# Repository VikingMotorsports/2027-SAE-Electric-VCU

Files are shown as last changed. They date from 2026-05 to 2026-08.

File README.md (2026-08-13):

# Formula SAE EV Vehicle Control System

A distributed **Vehicle Control System (VCS)** for a Formula SAE Electric racecar. The system uses STM32 microcontrollers running Zephyr RTOS for real-time vehicle control, a CAN bus for communication, and a Raspberry Pi for driver and remote telemetry displays.

> **Status:** Active Development

---

## System Overview

The VCS is currently built around two **STM32C092** modules and a Raspberry Pi.

- **Pedal Input Module** — Reads accelerator and brake pedal inputs and transmits them over CAN.
- **Motor Controller Module** — Receives pedal commands over CAN and generates PWM signals for the motor H-bridge.
- **Raspberry Pi Dashboard** — Receives CAN data and displays accelerator and brake inputs to the driver.
- **Remote Pit Dashboard** — Receives vehicle data from the Raspberry Pi over MQTT.

### Architecture

```text

     ┌──────────────────────┐			┌──────────────────────┐
     │   Brake Pedal        │			│   Accelerator Pedal  │
     └──────────┬───────────┘			└──────────┬───────────┘
				│								   │
				└─────────────────┬────────────────┘
                                  │
                                  ▼
                    ┌──────────────────────────┐
                    │   STM32C092              │
                    │   Pedal Input Module     │
                    │                          │
                    │   Zephyr RTOS            │
                    │   ADC → CAN              │
                    └────────────┬─────────────┘
                                 │
                                 │ CAN Bus
                                 │
                ┌────────────────┴────────────────┐
                │                                 │
                ▼                                 ▼
     ┌──────────────────────┐          ┌──────────────────────┐
     │   STM32C092          │          │   Raspberry Pi       │
     │   Motor Controller   │          │   Dashboard          │
     │                      │          │                      │
     │   CAN → PWM          │          │   CAN → Display      │
     └──────────┬───────────┘          └──────────┬───────────┘
                │                                 │
                │ PWM / Control                   │ MQTT
                ▼                                 ▼
     ┌──────────────────────┐          ┌──────────────────────┐
     │   Motor H-Bridge     │          │   Remote Pit         │
     │                      │          │   Dashboard          │
     └──────────────────────┘          └──────────────────────┘

````

---

## Hardware & Software

| Component | Description |
| --- | --- |
| **STM32C092** | Embedded vehicle control modules |
| **Zephyr RTOS**  | Real-time operating system for STM32 modules |
| **CAN Bus** | Communication between vehicle modules |
| **Raspberry Pi** | Dashboard and vehicle telemetry gateway |
| **Vulcan** | CAN interface between the vehicle network and Raspberry Pi |
| **MQTT** | Remote telemetry communication |
| **KiCad** | Electrical and PCB design |

---

## Repository Structure

```text
.
├── Dashboard/              # Raspberry Pi driver dashboard
├── Dashboard Webdisplay/   # Remote pit dashboard
├── Developers_Guide/       # Development documentation
├── PCB/                  	# PCB and electrical design files
├── MQTT/                   # MQTT communication
├── Vulcan/                 # CAN interface and configuration
├── Zephyr_apps/            # STM32C092 Zephyr applications
├── Zephyr_Scripts/         # Build, flash, and development scripts
├── .gitignore
└── README.md
```

---

## Communication

### CAN

The STM32 modules communicate over CAN. The Pedal Input Module sends accelerator and brake values to the CAN network, where they are received by the Motor Controller Module and Raspberry Pi.

```text
Pedal Module
     │
     ├── Accelerator
     └── Brake
          │
          ▼
       CAN Bus
       ┌────┴────┐
       ▼         ▼
Motor Controller  Raspberry Pi
       │             │
       ▼             ├──> Driver Dashboard
    PWM              │
       │             └──> MQTT
       ▼                    │
   H-Bridge                 ▼
                     Remote Pit Dashboard
```

### MQTT

The Raspberry Pi republishes selected CAN data over MQTT, allowing the pit crew to monitor vehicle information remotely.

---

## Current Functionality

The current system provides an end-to-end control and telemetry path:

* Accelerator and brake inputs are read by the Pedal Input Module.
* Pedal values are transmitted over CAN.
* The Motor Controller receives the commands and generates PWM output.
* The Raspberry Pi receives and displays pedal data on the driver dashboard.
* The Raspberry Pi broadcasts the same data over MQTT.
* A remote pit dashboard displays the transmitted vehicle data.

---

## Development

The system is designed to be modular, allowing additional vehicle control and monitoring functionality to be added as development continues.

### Planned Development

* [ ] Expand vehicle telemetry
* [ ] Add additional CAN messages
* [ ] Expand driver dashboard
* [ ] Expand remote pit monitoring
* [ ] Implement fault detection and reporting
* [ ] Add vehicle safety interlocks
* [ ] Develop dedicated VCS hardware
* [ ] Improve CAN diagnostics and logging
* [ ] Complete system-level testing

---

## Project Status

**Early Development / System Integration**

The basic vehicle control and telemetry pipeline is currently operational:

```text
Pedals
  ↓
STM32 Pedal Module
  ↓
CAN Bus
  ├──> STM32 Motor Controller ──> PWM ──> H-Bridge
  │
  └──> Raspberry Pi
          ├──> Driver Dashboard
          │
          └──> MQTT ──> Remote Pit Dashboard
```

Developed as part of a **Formula SAE Electric** racecar project.

```
```

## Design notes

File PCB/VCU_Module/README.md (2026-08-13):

# Viking Motorsports VCU Module

A custom STM32C092RCT6 development and vehicle-control PCB designed specifically for the Viking Motorsports Formula SAE Electric vehicle control system.

The board is designed to fit inside a **Cinch enclosure** and provide a flexible interface between the STM32 microcontroller and the vehicle's external wiring harness. Rather than creating a dedicated PCB for every vehicle-control function, this board provides a common hardware platform that can be configured for different VCU applications.

> **Status:** Hardware Development / Prototype

---

## Board Overview

The VCU Module is a Viking Motorsports-specific development board centered around the **STM32C092RCT6** microcontroller.

The board provides:

- STM32C092RCT6 microcontroller
- CAN bus interface
- Power and ground distribution
- Accessible MCU GPIO and peripheral pins
- Internal configuration headers
- 12-pin external connector
- 20-pin external connector
- Flexible mapping between MCU peripherals and external connector pins
- PCB designed around a Cinch enclosure

The primary design goal is **hardware reuse**. The same PCB can be used for different vehicle-control applications by changing the connections between the MCU peripheral headers and the external enclosure connectors.

---

## Design Concept

The VCU Module separates the vehicle wiring interface from the microcontroller's fixed pin assignments.

```text
                  ┌──────────────────────────────┐
                  │       STM32C092RCT6          │
                  │                              │
                  │   GPIO / ADC / PWM / CAN     │
                  └──────────────┬───────────────┘
                                 │
                         Internal Headers
                                 │
                  ┌──────────────┴───────────────┐
                  │                              │
                  │   User Configurable Wiring   │
                  │                              │
                  └──────────────┬───────────────┘
                                 │
                    ┌────────────┴────────────┐
                    │                         │
              ┌─────▼─────┐             ┌─────▼─────┐
              │ 12-Pin    │             │ 20-Pin    │
              │ Connector │             │ Connector │
              └─────┬─────┘             └─────┬─────┘
                    │                         │
                    └───────────┬─────────────┘
                                │
                       Vehicle Wiring Harness
````

The external connector pinout does not need to be permanently tied to a specific MCU peripheral.

Instead, the board provides internal headers that allow the desired MCU pins to be manually connected to:

* External connector pins
* Power
* Ground
* CAN signals
* Other required vehicle interfaces

This allows the same board design to support different VCU modules without requiring a new PCB layout for each application.

---

## External Interfaces

### 12-Pin Connector

The 12-pin connector provides one of the primary interfaces between the PCB and the vehicle wiring harness.

The individual pins can be assigned to the required MCU signals using the internal configuration headers.

Possible uses include:

* Digital inputs
* Digital outputs
* ADC inputs
* PWM outputs
* Power
* Ground
* Other low-voltage vehicle signals

The exact pin assignment is application-dependent.

### 20-Pin Connector

The 20-pin connector provides additional connections to the vehicle harness.

Like the 12-pin connector, its signals are configurable through the internal headers.

This allows the connector interface to be adapted for different VCU applications while keeping the PCB itself unchanged.

---

## Internal Configuration Headers

One of the primary features of the VCU Module is the collection of internal pin headers.

These headers expose the STM32 peripherals and allow them to be manually connected to the external connector pins.

The headers provide access to:

* MCU GPIO
* ADC-capable pins
* PWM-capable pins
* CAN signals
* 3.3 V / board power
* Ground

This configuration approach allows a single PCB design to be used for multiple vehicle-control modules.

For example, the same board could be configured as:

```text
Pedal Module
    │
    ├── ADC → Accelerator
    ├── ADC → Brake
    └── CAN → Vehicle Network
```

or:

```text
Motor Controller
    │
    ├── CAN → Vehicle Network
    ├── PWM → Motor H-Bridge
    └── GPIO → Control / Enable Signals
```

without changing the underlying PCB design.

---

## CAN Interface

The board includes a dedicated CAN interface for communication with the vehicle control network.

The CAN interface provides:

* CAN TX
* CAN RX
* CAN bus connections
* Access to CAN signals through the board's internal configuration system

The VCU Module is intended to operate as a node on the Formula SAE Electric vehicle CAN network.

CAN message definitions and vehicle communication protocols are documented separately in the main VCU repository.

---

## Power

The board includes dedicated power circuitry and power distribution for the STM32 and associated peripherals.

Power and ground are also made accessible through the internal headers so that external signals can be configured without requiring additional wiring to the PCB.

The power section is separated into its own KiCad schematic sheet for clarity.

---

## Schematic Organization

The KiCad project is divided into several schematic sections:

```text
VCU_Module.kicad_sch
│
├── MCU.kicad_sch
│   └── STM32C092RCT6 and MCU peripherals
│
└── POWER.kicad_sch
    └── Power input and power distribution
```

The top-level `VCU_Module.kicad_sch` integrates the individual schematic sections into the complete board design.

---

## Intended Use

This board is intended to serve as the standard **Viking Motorsports VCU development platform**.

The goal is to avoid designing a new PCB whenever a new vehicle-control function requires a different combination of MCU peripherals.

Instead:

1. Select the required MCU peripherals.
2. Connect those peripherals to the appropriate internal headers.
3. Connect the headers to the desired external connector pins.
4. Install the board into the Cinch enclosure.
5. Develop the corresponding Zephyr application.

This creates a common hardware platform for future VCU development.

---

## Example Applications

The board can be configured for a variety of vehicle-control functions, including:

### Pedal Input Module

```text
Accelerator ──> ADC
Brake ────────> ADC
CAN ──────────> CAN Interface
```

### Motor Controller Module

```text
CAN ──────────> CAN Interface
PWM ──────────> Motor H-Bridge
GPIO ─────────> Enable / Control
```

### Future VCU Modules

The configurable hardware architecture allows future modules to be developed without creating a completely new PCB for each function.

---

## Enclosure

The PCB is designed to fit within a **Cinch 5810130065 4x3.35 ME enclosure** and utilizes the **Cinch 5810132011 32 pos. ME-MX header**

The external 12-pin and 20-pin Molex MX150 connectors provide the interface to the vehicle wiring harness while the configurable headers remain accessible inside the enclosure.

This provides a clean separation between:

* Vehicle wiring
* PCB hardware
* MCU peripheral assignment
* Firmware configuration

---

## Development Status

**Current Status: Prototype / Hardware Development**

The KiCad project currently contains a complete schematic and PCB design for the VCU Module.

Before deployment in the vehicle, the design should undergo:

* Electrical design review
* KiCad ERC verification
* PCB DRC verification
* Connector pinout verification
* Power integrity testing
* CAN interface testing
* MCU programming/debug testing
* Enclosure fit verification
* Vehicle-level testing

The connector pin assignments should be considered **application-specific** until finalized for a particular VCU module.

---

## Related Software

Firmware for the STM32C092-based vehicle control modules is located in the main repository under:

```text
Zephyr_apps/
```

The VCU software currently includes separate applications for vehicle-control functions such as the pedal input and motor controller modules.

---

## Design Philosophy

The VCU Module is designed around three principles:

**Reusable Hardware**
One PCB can support multiple vehicle-control applications.

**Configurable Interfaces**
MCU peripherals can be mapped to the external connector pins using internal headers.

**Vehicle Integration**
The board provides a consistent physical and electrical interface for the Viking Motorsports vehicle control system.

---

**Viking Motorsports — Formula SAE Electric**

*Custom hardware for the 2027 SAE Electric Vehicle Control System.*

## Documentation Links

*https://www.cinch.com/products/enclosures/enclosures/5810130065*

*https://www.cinch.com/products/enclosures/headers/5810132011*

*https://www.st.com/en/microcontrollers-microprocessors/stm32c092rc.html*

## Documentation Files

| Filename | Notes |
| --- | --- |
| README.pdf | This README file |
| VCU_Module-outline.dxf | Board outline (with holes) in DXF format |
| VCU_Module-pcba.step | 3D model of PCBA (with components) |
| VCU_Module-render-bot.jpg | Render of the top of the 3D model |
| VCU_Module-render-bot.jpg | Render of the bottom of the 3D model |
| VCU_Module-schematic.pdf | PDF of board schematics |

## Contact Information

- Website: *website*
- Email: *email*

## Board Renders

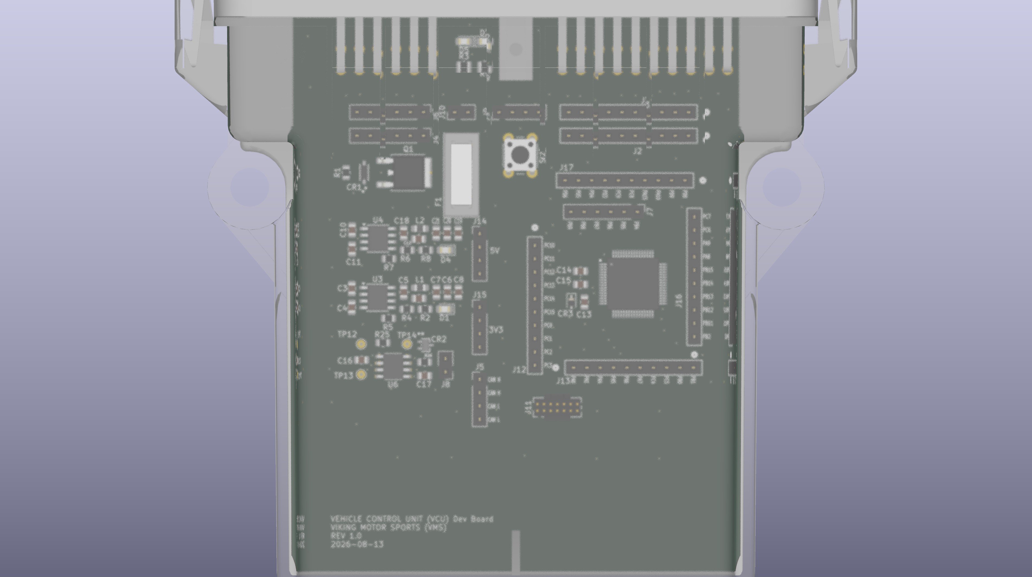
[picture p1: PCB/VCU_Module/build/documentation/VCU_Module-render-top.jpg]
Render of the top of the 3D model

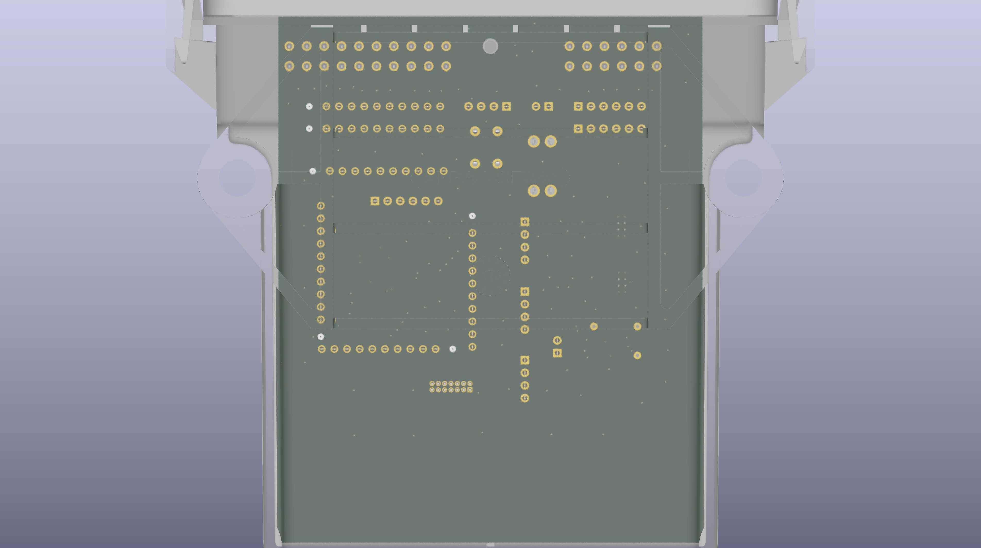
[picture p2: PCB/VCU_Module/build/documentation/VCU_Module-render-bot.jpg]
Render of the bottom of the 3D model


\newpage

# Printed Circuit Board (PCB) Fabrication Information

---
title: "**Viking MotorSports VCU Module**"
subtitle: |
  **Fabrication and Assembly Information**\
  For build TIME-STAMP
fontsize: 10pt
geometry:
  - margin=0.5in
toc: true
toc-depth: 2
colorlinks: true
urlcolor: blue
---

## Board Info

- 2 layer board
- Bounding box is *TBD*
- Board thickness is 1.59 mm (0.063 inch)

## Board Requirements

- Design Rules
    - Minimum Trace / Space design rulea: 0.1524 mm (6.0 mil) / 0.1524 mm (6.0 mil)
    - Outer dimension router tolerance: +/- 0.254 mm (10.0 mil)
    - Hole placement tolerance: +/- 0.075 mm (3.0 mil)
- Drills
   - Drill Positional Tolerance: 0.051 mm (2.0 mil)
   - Drill Size tolerance: +/- 0.064 mm (2.5 mil)
- Plated/Un-plated holes
  - There are no un-plated (NPT) holes
  - There are 96 plated through (PTH) holes
  - PTH minimum diameter: 0.254 mm (10 mil)
  - PTH minimum annulus: 0.102 mm (4 mil) radius
- Outline/Routing
  - No requirements.
- Slots
  - There are no slots.
- Cutouts
  - There are no cutouts
- There are 3 fiducials on the top layer.
- Panel tabs ("mouse bites")
   - Card edges must be smooth; no mouse bites or other intrusions into the card outline.
   - If external mouse bites are required, minimize and customer will remove by hand before assembly.
- If not otherwise specified, build to IPC 6012 Class 2 or better.

## Materials

- No requirements for materials.
- Copper Surface treatment should be ENIG, althogh immersion Silver is acceptable.
- White silkscreen on top and bottom surface
- Taiyo PSR-4000 or equivalent soldermask on top and bottom, no requirements for color.

## Stack Up

- Any FR4 like material is acceptable.
- 1 oz Copper on top and bottom layers
- 1.6 mm thick when done (1/16 inch)

## Array / Panel Information

- Coordinate with Contract Manufacturer (CM) for optimal size of this panel.
- If no feedback from CM, then produce single boards (no panel).

## Fabrication Files

### IPC-2581 File

| Filename | Notes |
| --- | --- |
| VCU_Module-ipc2581.xml | IPC-2581 board information file |

### Legacy PCB Files

| Filename | Notes |
| ---| --- |
| VCU_Module-Edge_Cuts.gbr | RS274X file for the dimension (outline) layer |
| VCU_Module-F_Silkscreen.gbr | RS274X file for the top silkscreen |
| VCU_Module-F_Mask.gbr | RS274X file for the top soldermask |
| VCU_Module-F_Cu.gbr | RS274X file for the top copper layer |
| VCU_Module-In1_Cu.gbr | RS274X file for the layer 2 copper |
| VCU_Module-In2_Cu.gbr | RS274X file for the layer 3 copper |
| VCU_Module-B_Cu.gbr | RS274X file for the bottom copper layer |
| VCU_Module-B_Mask.gbr | RS274X file for the bottom soldermask |
| VCU_Module-B_Silkscreen.gbr | RS274X file for the bottom silkscreen |
| VCU_Module-NPTH.drl | Excellon file for non-plated through holes |
| VCU_Module-PTH.drl | Excellon file for plated through holes | 

\newpage

# Printed Circuit Board Assembly (PCBA) Information

## Assembly Info

- All components are on the top side of the board.
- This PCBA has two components that are SMT components with through-hole mechanical leads.

## Assembly Requirements

- Assemble to IPC Class 2 or better
- Solder paste can be ROHS or leaded.
- No clean, or Aqueous flux and wash, can be used.
- No conformal coating.

## Component Specific Assembly Information

- None

## Assembly Files

### IPC-2581 File

| Filename | Notes |
| --- | --- |
| VCU_Module-ipc2581.xml | IPC-2581 board information file |

### Bill of Materials (BOM)

| Filename | Description |
| --- | --- |
| VCU_Module-bom.csv | BOM in Comma Separated Variable format |

### Solder Paste Stencils

| Filename | Notes |
| --- | --- |
| VCU_Module-B_Paste.gbr | RS274X file for top/front solder paste stencil |
| VCU_Module-F_Paste.gbr | RS274X file for bottom/back solder paste stencil |

### Mounting/Placement Location

| Filename | Description |
| --- | --- |
| VCU_Module-3u.pos | Pick and place locations for components |

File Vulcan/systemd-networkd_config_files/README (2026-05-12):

This config file tells the linux system to automatically configure and initialize the can0 device on startup and/or hotplug

save the .network file in this folder into /etc/systemd/network/

Then run the following command:

sudo systemctl restart systemd-networkd

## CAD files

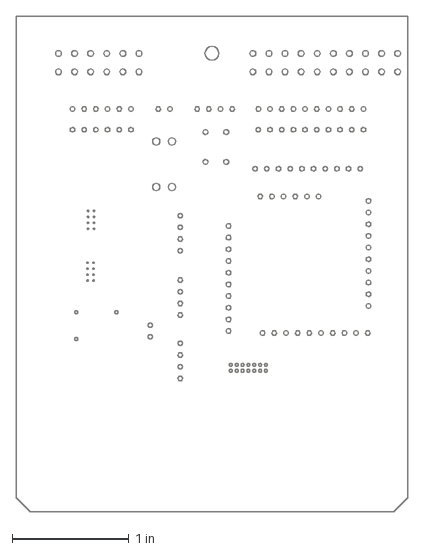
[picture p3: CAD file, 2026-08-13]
PCB/VCU_Module/build/documentation/VCU_Module-outline.dxf
3.35 x 4.25 in

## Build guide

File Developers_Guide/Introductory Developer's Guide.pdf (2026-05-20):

Hello new developer! Here’s your guide to getting started with writing firmware for the VMS VCU

### system!

### A couple orders of business before starting, here’s the tools we’re going to use:

- STM32C092RC boards STM32C092RC | Product - STMicroelectronics (https://www.st.com/en/microcontrollers-microprocessors/stm32c092rc.html)
- Zephyr RTOS Getting Started Guide — Zephyr Project Documentation (https://docs.zephyrproject.org/latest/develop/getting_started/index.html)
- Your choice IDE (VS Code always a favorite) Tutorial: Get started with Visual Studio Code (https://code.visualstudio.com/docs/getstarted/getting-started)
- CAN FD communication protocol Microchip University CAN (https://mu.microchip.com/page/interface)

These tools were chosen for their versatility, price, featureset, and ease of development. It’s recommended that you at least look at the C0 datasheet, learn how to set up Zepyhr dev tools and the flashing utility, get familiar with your IDE, and at least watch the CAN basics course in full if not the CAN development course before continuing. “Give me six hours to chop down a tree and I’ll spend the first four sharpening the axe.” - Lincoln, presumably.
The Zephyr getting started guide is a great starting point for setting up development tools, however to break into CAN the Zephyr CAN driver page is an excellent resource with CAN samples that can be built upon.
- Zephyr CAN page: Controller Area Network (CAN) — Zephyr Project Documentation (https://docs.zephyrproject.org/latest/hardware/peripherals/can/index.html)
- CAN samples main: zephyr/samples/drivers/can at main · zephyrproject-rtos/zephyr · GitHub (https://github.com/zephyrproject-rtos/zephyr/tree/main/samples/drivers/can) In the samples (“samples” under the CAN controller title) there is a counter and a babbling example. Either of these examples are a good base for creating a CAN program that can filter and send messages on a bus.

Zephyr RTOS was partially chosen for the ability to use the CAN controller in real-time though the CAN shell.

### - Zephyr Shell basics: https://dev.blues.io/blog/zephyr-use-shells-for-prototyping/ - Using Zephyr and Shell on Linux: https://michaelangerer.dev/zephyr/2023/02/12/zephyr-basics-shell.html

- Zephyr Shell Official Site: https://docs.zephyrproject.org/latest/services/shell/index.html

### - CAN shell commands: https://docs.zephyrproject.org/latest/hardware/peripherals/can/shell.html how

## Reading Sensors

At this point you should already have gone through the Zephyr RTOS Getting Started Guide — Zephyr Project Documentation. (https://docs.zephyrproject.org/latest/develop/getting_started/index.html) If not, do this first and get blinky running on your board.

Next, download the appropriate documentation for the board you are using, below you will find the datasheets for the nucleo c092rc (MB2046)

Nucleo_c092rc board user manual: https://www.st.com/resource/en/user_manual/um3353-stm32-nucleo64-board-mb2046-stmicroel ectronics.pdf (https://www.st.com/resource/en/user_manual/um3353-stm32-nucleo64-board-mb2046-stmicroelectronics.pdf)
Zephyr documentation for Nucleo_c092rc board: https://docs.zephyrproject.org/latest/boards/st/nucleo_c092rc/doc/index.html

### Potentiometer

We will set up the board to read from a potentiometer using one of the boards analog inputs paired with an adc sample. The following steps will get you started:

1.) Navigate to your zephyr project directory and find the adc_dt sample, this should be in <zephyrproject>/zephyr/samples/drivers/adc/adc_dt.

2.) Open the boards folder to see if there is an existing overlay for your board. If so, skip to step 4, if not we will make one.

3.) Create board Overlay: The board overlays help make zephyr more portable by allowing you to define key parameters for the board you are using without having to modify the main source code.
a.) First, copy a similar board overlay and rename it to match your board, I copied the nucleo_c071rb and renamed it to nucleo_c092rc

b.) Next, Open the overlay and find the section that defines the adc input channels which should look like this:

c.) find your boards dts file, in <zephyrproject>/zephyr/boards/ (for c092rc, it should be <zephyrproject>\zephyr\boards\st\nucleo_c092rc\nucleo_c092rc.dts)

The dts file defines hardware configuration for the board, including peripheral routing. We need to find what pins are connected to the adc by default.

d.) Here is a sample from the c092 .dts file:

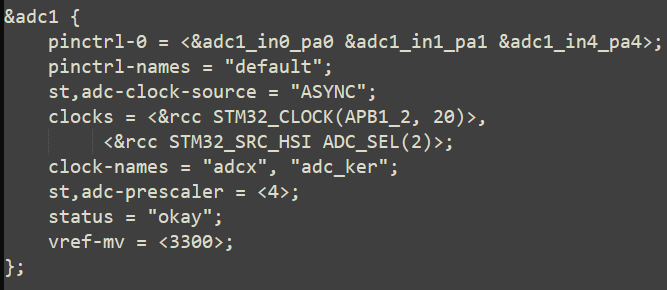
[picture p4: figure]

As you can see, the &adc1 peripheral is configured as an input to pa0, pa1, pa4
This matches the definitions in the c071 overlay which I copied, so no changes were needed. However, if you needed or wanted to change the input ports this is where you would do it.

4.) You now should have a board overlay for your board. If you haven't already, find and open your boards dts file in <zephyrproject>/zephyr/boards/ and find the adc peripheral section. Take note of the pin names that it is connected to. (for c092rc example above, pa0, pa1, pa4)

5.) Open the documentation for your board and search the pin names that you just found and note their location on the board. Also take note of the input range! (for c092rc, user-manual (https://www.st.com/resource/en/user_manual/um3353-stm32-nucleo64-board-mb2046-stmicroelectronics.pdf) page 23, CN7/Pins 28,30,32)

6.) Finally, connect your sensor to one of the pins you identified, build and flash adc_dt sample, and use the serial monitor of your choice to monitor the output. You should see something like the image below

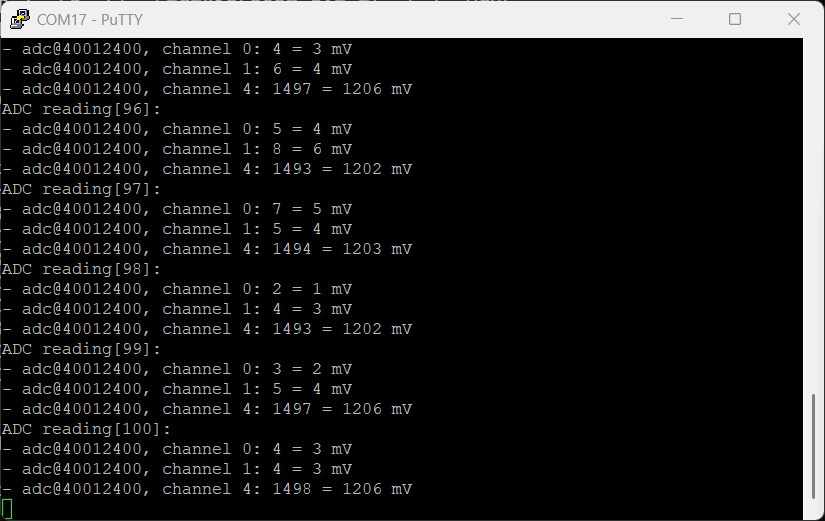
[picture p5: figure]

## ADC Input -> CAN Message

Before starting on this, you should have loaded and successfully ran both the adc and CAN counter samples on your board. Now we will combine these two samples into a new application that transmits input data onto the CAN bus.

1. First, create a copy of the can counter sample folder and rename it whatever you like. It should have the source code, boards folder, config files, etc.
2. Now we need to add all of the stuff in order to use ADC functionality in the application. This just means copying dissimilar things over from the adc_dt sample but here’s a list of things to change:
a. Boards folder: copy the overlay for your board from adc_dt to the new app
b. CMakeLists: add ADC package to the list of required packages
c. Kconfig: add ADC calibration requirement
d. prj.conf: add ‘CONFIG_ADC=y’
3. With the ADC functionality now enabled and configured for use in the new app, we can move on to the source code.

Copy everything from the adc_dt main that is not already in our main file. There are some new header files and definitions, a function called adc_dt_spec, and all of the code in main to configure and read from the ADC.

Within the main function, I put the ADC reading code inside the while(1) loop, after the change led section and before the counter message.

4. At this point, you should have an app that builds and runs but it will be printing the ADC values to the terminal directly instead of over CAN and it will still be sending the counter messages over the bus. Modify the main.c as follows:
a. Comment out all of the print statements in the while 1 loop
b. Move the can_send and UNALIGNED_PUT calls inside of the adc loop at the end
c. Change the UNALIGNED_PUT command for the counter message so that it uses val_mv (adc_input) instead of ‘counter’
d. Scroll up and find the rx_thread function. Everything should be functional as it is, but you can change the print statements so they output more appropriate messages like ‘adc value received’ or whatever you like.

This is the function where you filter messages and define what to do with those messages when you receive them.

5. Finally, build and flash to your board and your board should now read an adc input and output it onto the CAN bus

## Receiving CAN Messages

In order to receive data we need to create a filter for the desired message id, add that id to the message queue, and define what to do with it once it is received.

First, we need to create the new message ID, you should see something like this at the top of an existing CAN app:

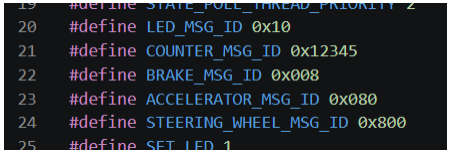
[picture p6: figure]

You can define the new message however you want, just remember that the message ID contains an implicit priority with lower IDs getting serviced first

Next, in the rx_thread function you should see an existing filter struct that looks like this

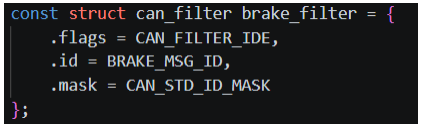
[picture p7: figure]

TBD/Maybe not needed since we moved to Vulcan

## Setting up vulcan and candlelight socketCAN

See the copperforge vulcan documentation here: https://copperforge.cc/docs/index.html For initial setup of the vulcan.

Download the latest .bin file from the candlelight page https://gitlab.com/Copperforge/Public/vulcan_firmware/vulcan_fw_candlelight/-/releases/

SocketCAN can only be run on a linux system, we have yet to figure out how to get it to work on windows.

On your linux system you will need to install can-utils and dfu-util which can be done be running the following commands

Sudo apt install dfu-util
Sudo apt install can-utils

Then just follow the copperforge setup guide to flash the candlelight socketCAN software to the vulcan

## Using socketCAN device

Once you have flashed the vulcan with the software, you should be able to see the can device on your system to check. In the terminal, run:

ip link show

For more information, run

ip -details link show can0

This will tell you bitrate, samplepoint, and other configuration information on the device

This should show all of the network devices available and you should now have a device labeled “can0”

If this is your first time plugging it in, it will show “down” meaning it is inactive

To activate the can device run the command

sudo ip link set can0 up type can bitrate 500000

Now if you run ip -detatils link show can0 again, you should see that the bus is “up” and bitrate is set for 500000.

You should also see that the status is “ERROR-ACTIVE” which means the CAN bus is working properly.

You can now run candump can0 in one terminal window while you send can messages in a separate window using cansend can0 <MSG_ID>#<PAYLOAD>

For example,
Cansend can0 123#deadbeef

Which should display a message with ID 123 and data bytes DE AD BE EF in the candump window.

If it any time messages are not making it through, check to see if the bus status is “ERROR-PASSIVE” using the ip -details link command. This means that the device has received too many error messages and has errored out.

You can reset the bus by running
sudo ip link set can0 down
Then
sudo ip link set can0 up

You now have a functioning CAN network device, yay!

## Configuring auto initialize for socketCAN device

To have the CAN bus automatically initialize we added a systemd-networkd file to tell the linux system to bring the bus up when it is recognized. This works for hotplugging the vulcan too!

In the VCU GitHub, find the configuration file labeled “80-can.network”

Copy this file to your system network files by running the following

sudo cp 80-can.network /etc/systemd/network/

Then run the command

sudo systemctl restart systemd-networkd

Your can device should now be activated and your linux system should automatically bring the CAN bus up on startup or hotplug.

Confirm that the bus is active and working by ensuring that it says “UP” and “ERROR-ACTIVE” when you run ip -details link show can0

## Using SocketCan on Windows

This is kind of a pain and not at all necessary but if you are determined to develop on a windows system like I was then it isn't too hard to get set up.

You should probably know a little bit about building a Linux kernel before attempting but the guide below is pretty easy to follow regardless.

https://gist.github.com/manavortex/cdaf9540784808e5848cbec744d49a19

I had a couple issues when doing this:

1.) I was missing a tool required for building the kernel (it will throw an error during building and tell you which module is missing)
2.) The CAN device drivers menu was on a different page than what they show in the guide. (for me, it was in device drivers -> networking drivers -> CAN drivers, or something like that)
3.) You will also want to enable the usb-CAN driver that your device uses, for candlelight socketCAN on the vulcan, it is gs_usb (Geschwister Schneider)

Other than that, you will need to use the windows usbipd tools to attach usb devices to WSL

Usbipd list (to find bus id)
Usbipd bind -b <bus-id>
Usbipd -w -b <bus-id>

Then if you should see the device in WSL using lsusb and ip link show.

## Writing a New Module using VCUmodule in Zephyr

This application is designed to split up all of the functionality needed for the entire car into separate .c/.h files so that you can only include what is necessary for a specific module. Each API contains essential functions for setting up and using that specific feature.

More information on specific features can be found in the .h and .c files

See the following outline for writing a new module.

1.) Copy VCUmodule to your zephyr workspace

2.) At the time of writing this, the nucleo_c092rc is the only board that we have written an overlay for. If you are using a different board, you will need to create a new one specific to your board that supports the functionality desired.

3.) Open the CMakeLists.txt file, you should see something like this:

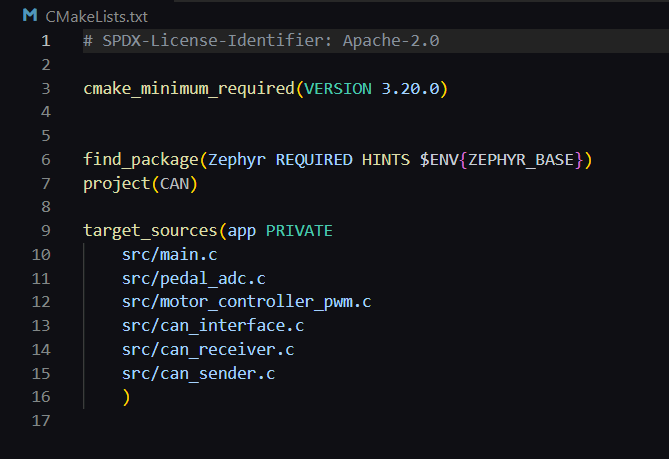
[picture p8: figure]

This is where you will tell CMake which .c files you will be using for your module. You can delete the ones not needed for your module.
Similarly, you can add/remove the .h files from main as needed

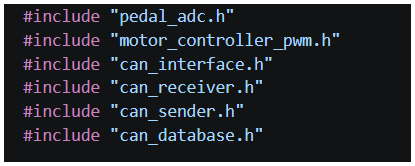
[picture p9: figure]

4.) Now you are ready to write main and add any functionality needed for the new module.

The main.c that you started with should serve as a good example of how to interact with the various APIs but each one also has fairly good documentation inside for where to add stuff.

5.) CAN Functionality

It should be fairly straightforward getting CAN functionality added with the APIs as they are well commented, but I’ll explain each file briefly since there are a few.

can_database.h
This file simply contains the CAN message IDs and and comments about how they are used

can_interface
This contains all generic CAN initialization and is needed if CAN functionality will be utilized in the module

can_receiver
Contains functions for receiving data over the CAN bus. This is only needed if you need to receive messages from the bus.

Inside you will have to define filters for any message IDs that you add in order to receive them

Optionally, you can define what to do when specific messages are received here as well

can_sender
Contains functions for sending data over the CAN bus. This is only needed if you are sending data over the bus.

You should define CAN frames for the MSG IDs you are sending here. The sending function will default to 8 byte payload, std 11-bit ID, etc. if not defined.

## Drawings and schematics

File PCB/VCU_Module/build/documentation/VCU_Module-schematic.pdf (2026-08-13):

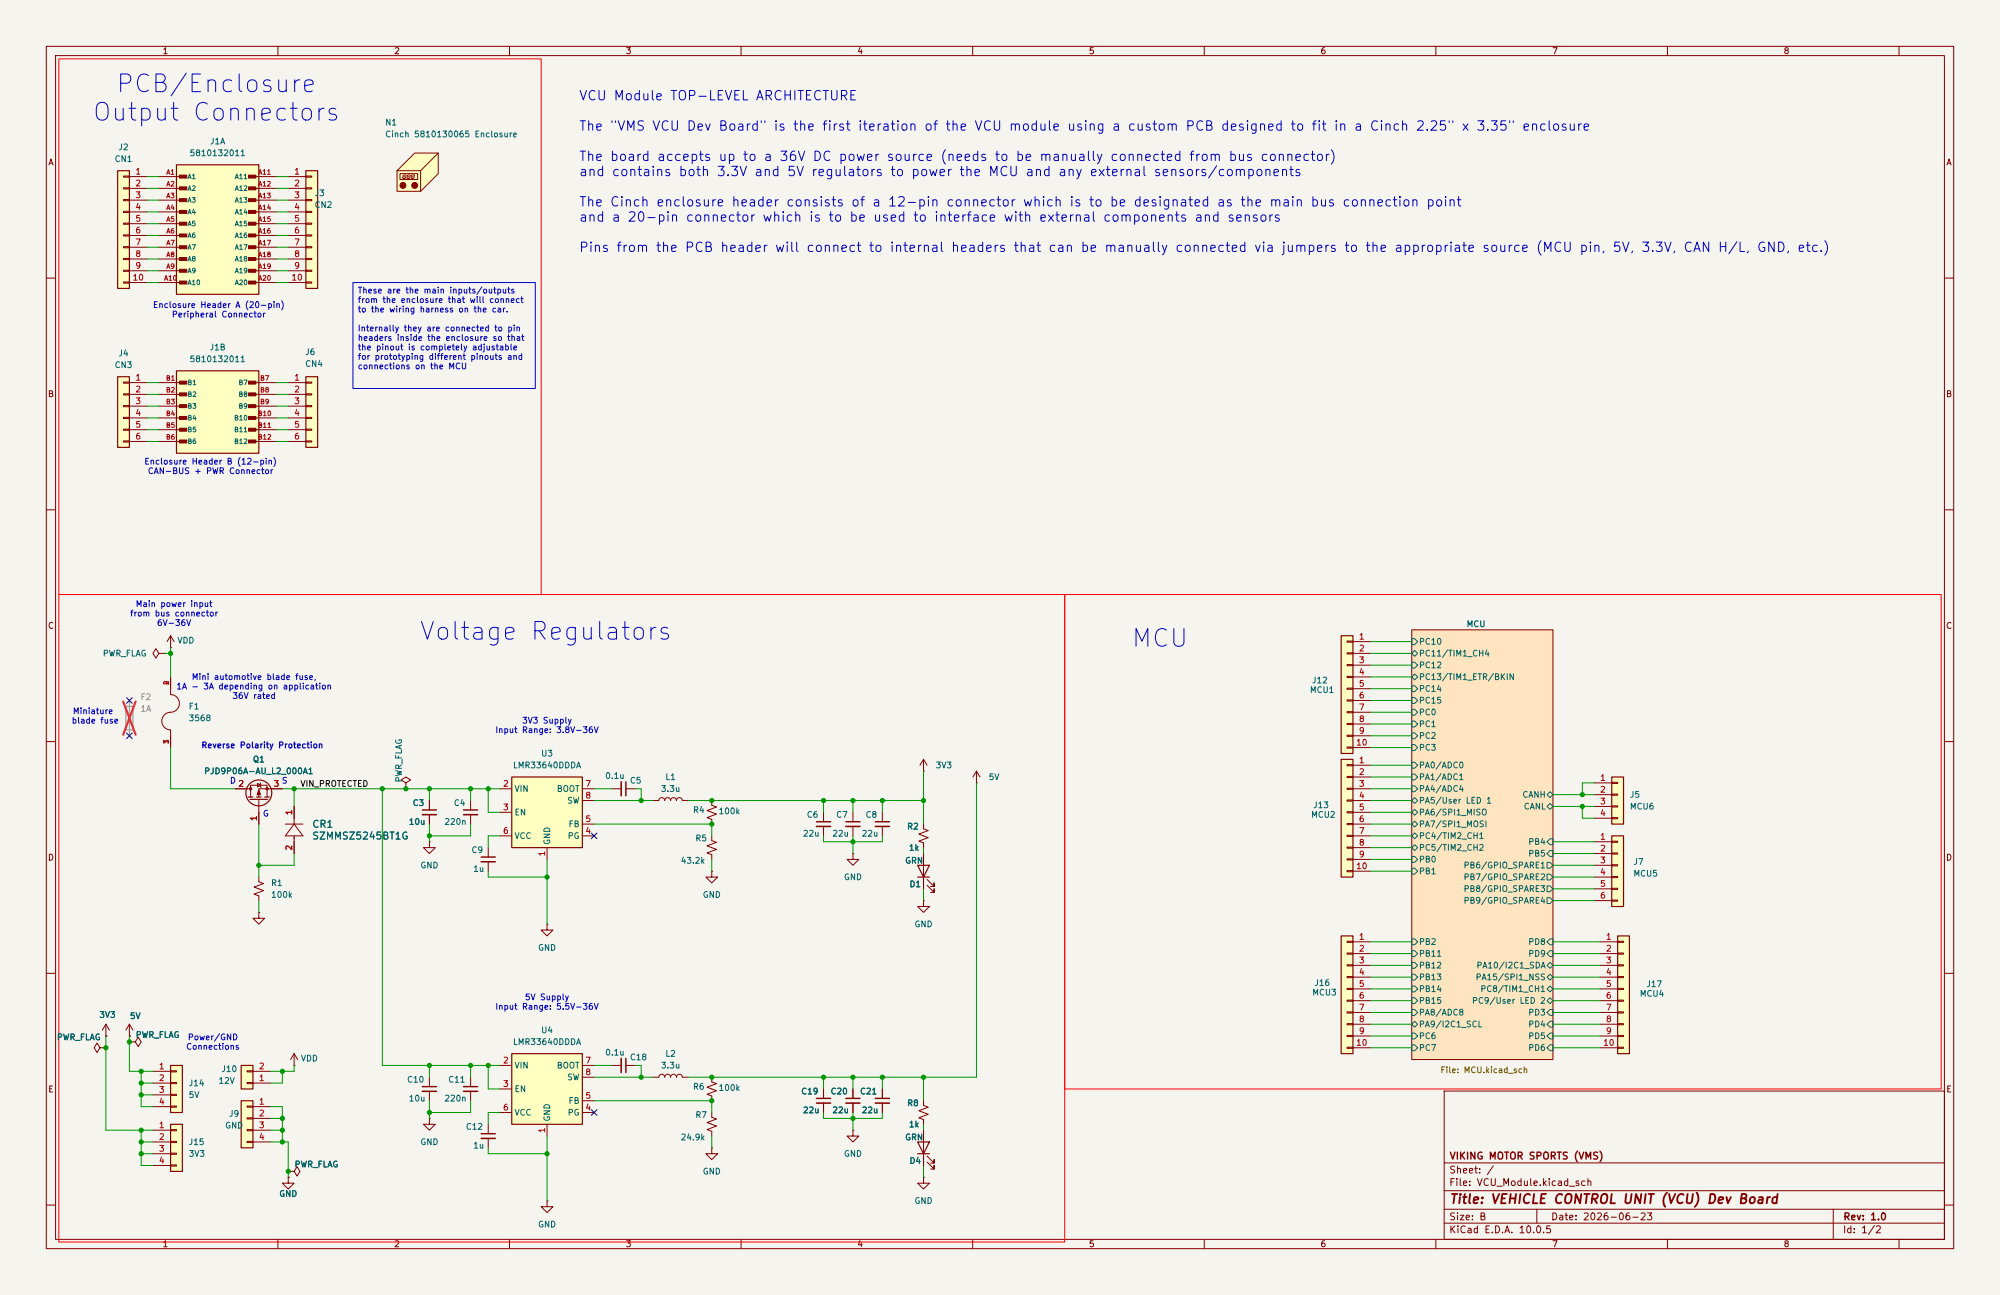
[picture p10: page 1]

Peripheral Connector PCB/Enclosure
Output Connectors

VCU Module TOP-LEVEL ARCHITECTURE

The "VMS VCU Dev Board" is the first iteration of the VCU module using a custom PCB designed to fit in a Cinch 2.25" x 3.35" enclosure

The board accepts up to a 36V DC power source (needs to be manually connected from bus connector)
and contains both 3.3V and 5V regulators to power the MCU and any external sensors/components

The Cinch enclosure header consists of a 12-pin connector which is to be designated as the main bus connection point
and a 20-pin connector which is to be used to interface with external components and sensors Pins from the PCB header will connect to internal headers that can be manually connected via jumpers to the appropriate source (MCU pin, 5V, 3.3V, CAN H/L, GND, etc.)

These are the main inputs/outputs
from the enclosure that will connect
to the wiring harness on the car.

Internally they are connected to pin
headers inside the enclosure so that
the pinout is completely adjustable
for prototyping different pinouts and
connections on the MCU Voltage Regulators

Main power input
from bus connector 6V-36V Reverse Polarity Protection D Mini automotive blade fuse, 1A - 3A depending on application 36V rated
LMR33640DDDA GND

PB9/GPIO_SPARE4 PB11 PB12 PB13 PB14 PB15 PC0 PC1 PC2 PC3 PC4/TIM2_CH1
VIKING MOTOR SPORTS (VMS) CANH

10 | 10

Sheet: /
File: VCU_Module.kicad_sch
Title: VEHICLE CONTROL UNIT (VCU) Dev Board

Size: B | Rev: 1.0
KiCad E.D.A. 10.0.5 | Id: 1/2

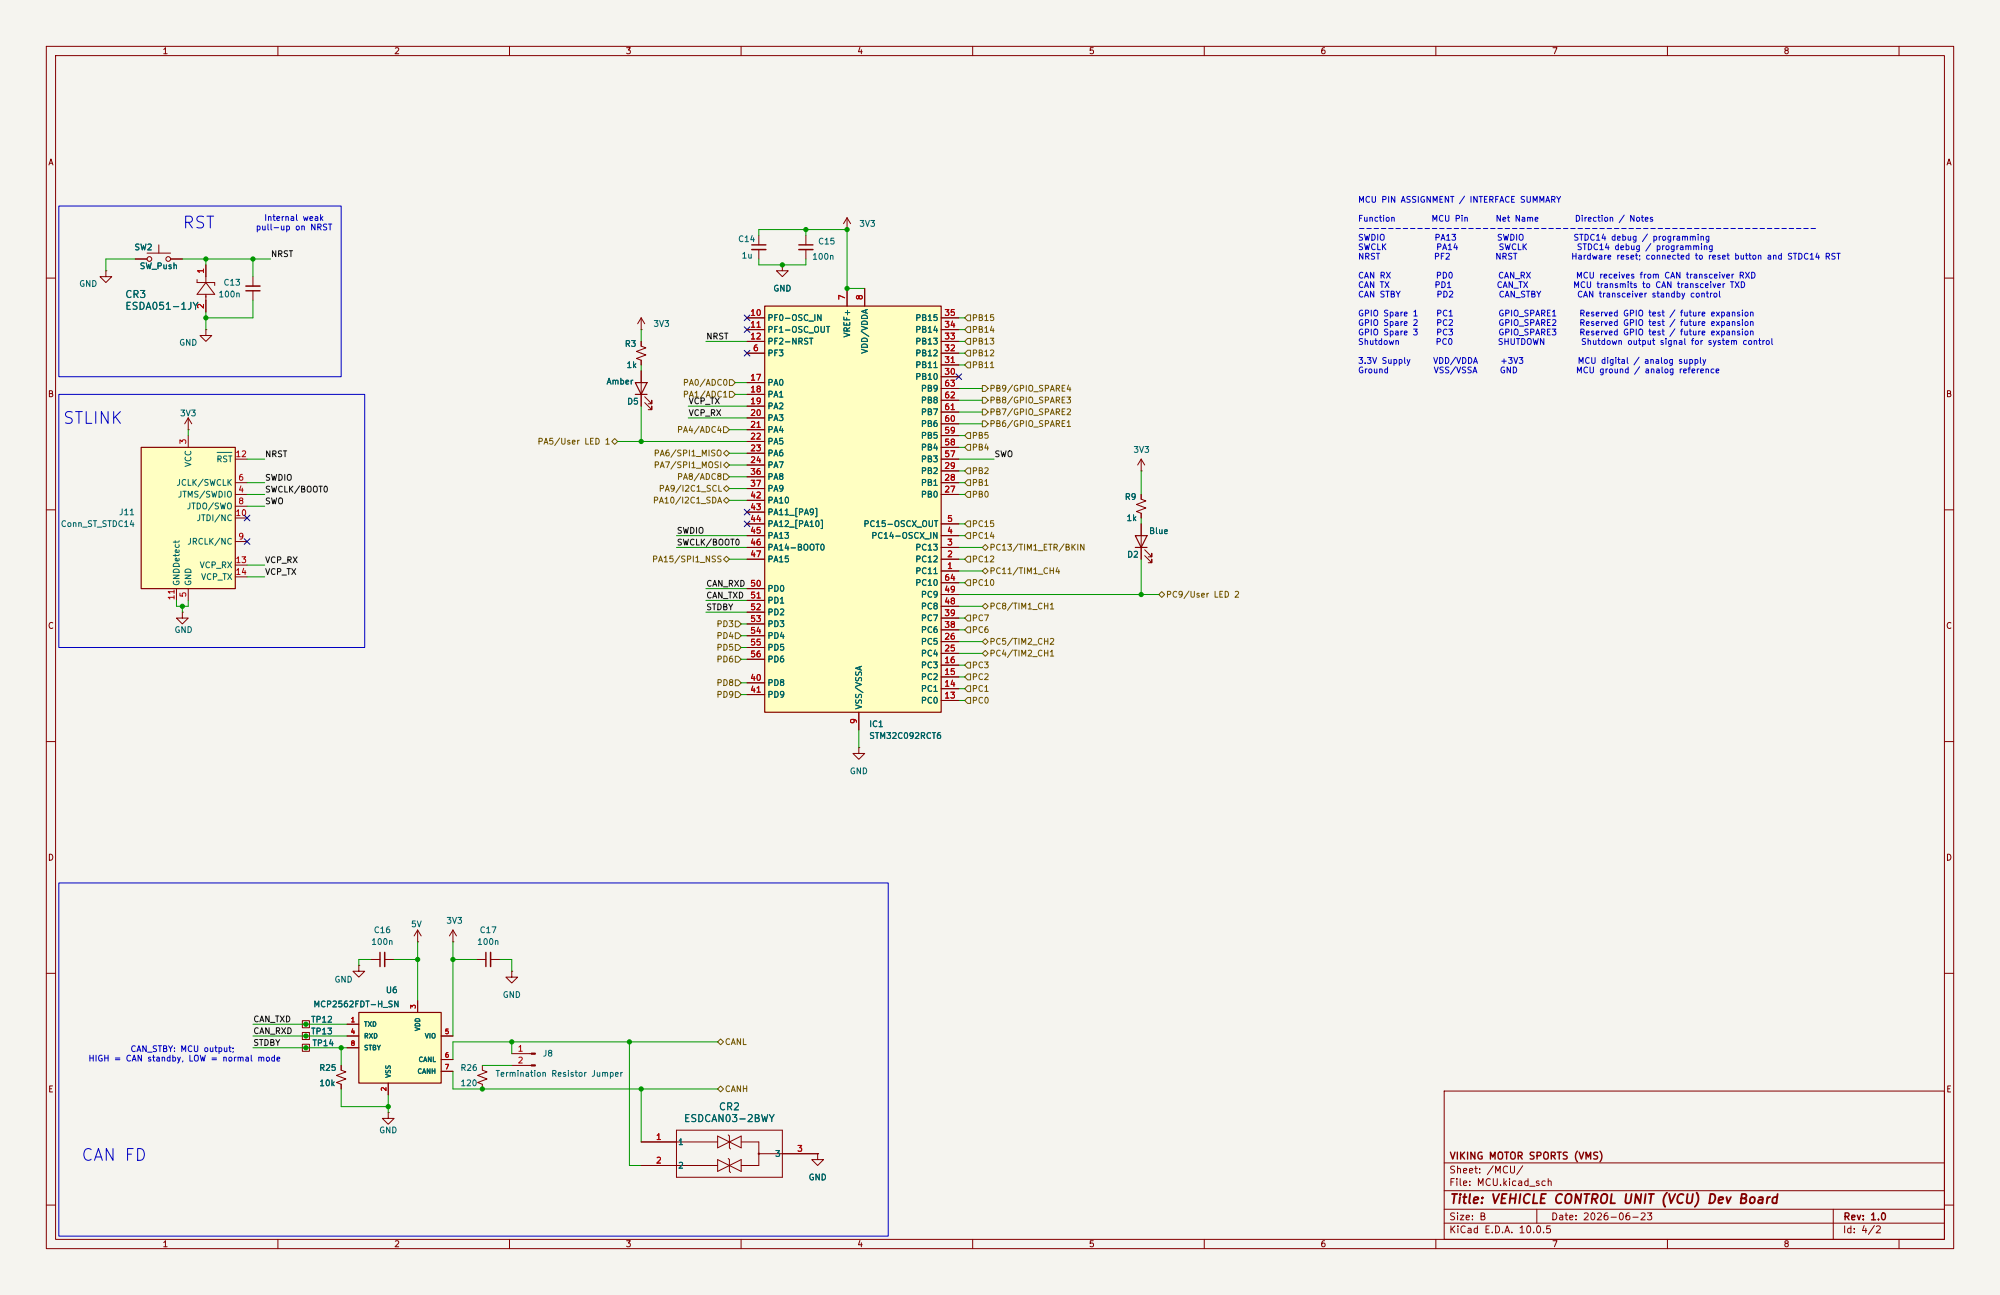
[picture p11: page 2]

CAN_STBY: MCU output; HIGH = CAN standby, LOW = normal mode STLINK

7 VDD/VDDA 8 VSS/VSSA 9 PF0-OSC_IN 10 PF1-OSC_OUT 11 PF2-NRST 12 PC0 13 PC1 14 PC2 15 PC3 16 PA0 17 PA1 18 PA2 19 PA3 20 PA4 21 PA5 22 PA6 23 PA7 24 PC4 25 PC5 26 PB0 27 PB1 28 PB2 29 PB10 30 PB11 31 PB12 32 PB13 33 PB14 34 PB15 35 PA8 36 PA9 37 PC6 38 PC7 39 PD8 40 PD9 41 PA10 42 PA11_[PA9] 43 PA12_[PA10] 44 PA13 45 PA14-BOOT0 46 PA15 47 PC8 48 PC9 PD0 49 50 PD1 51 PD2 52 PD3 53 PD4 54 PD5 55 PD6 56 PB3 57 PB4 58 PB5 59 PB6 60 PB7 61 PB8 62 PB9 63 PC10 64 GND

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

VIKING MOTOR SPORTS (VMS)
Sheet: /MCU/
File: MCU.kicad_sch
Title: VEHICLE CONTROL UNIT (VCU) Dev Board

Size: B | Rev: 1.0
KiCad E.D.A. 10.0.5 | Id: 4/2

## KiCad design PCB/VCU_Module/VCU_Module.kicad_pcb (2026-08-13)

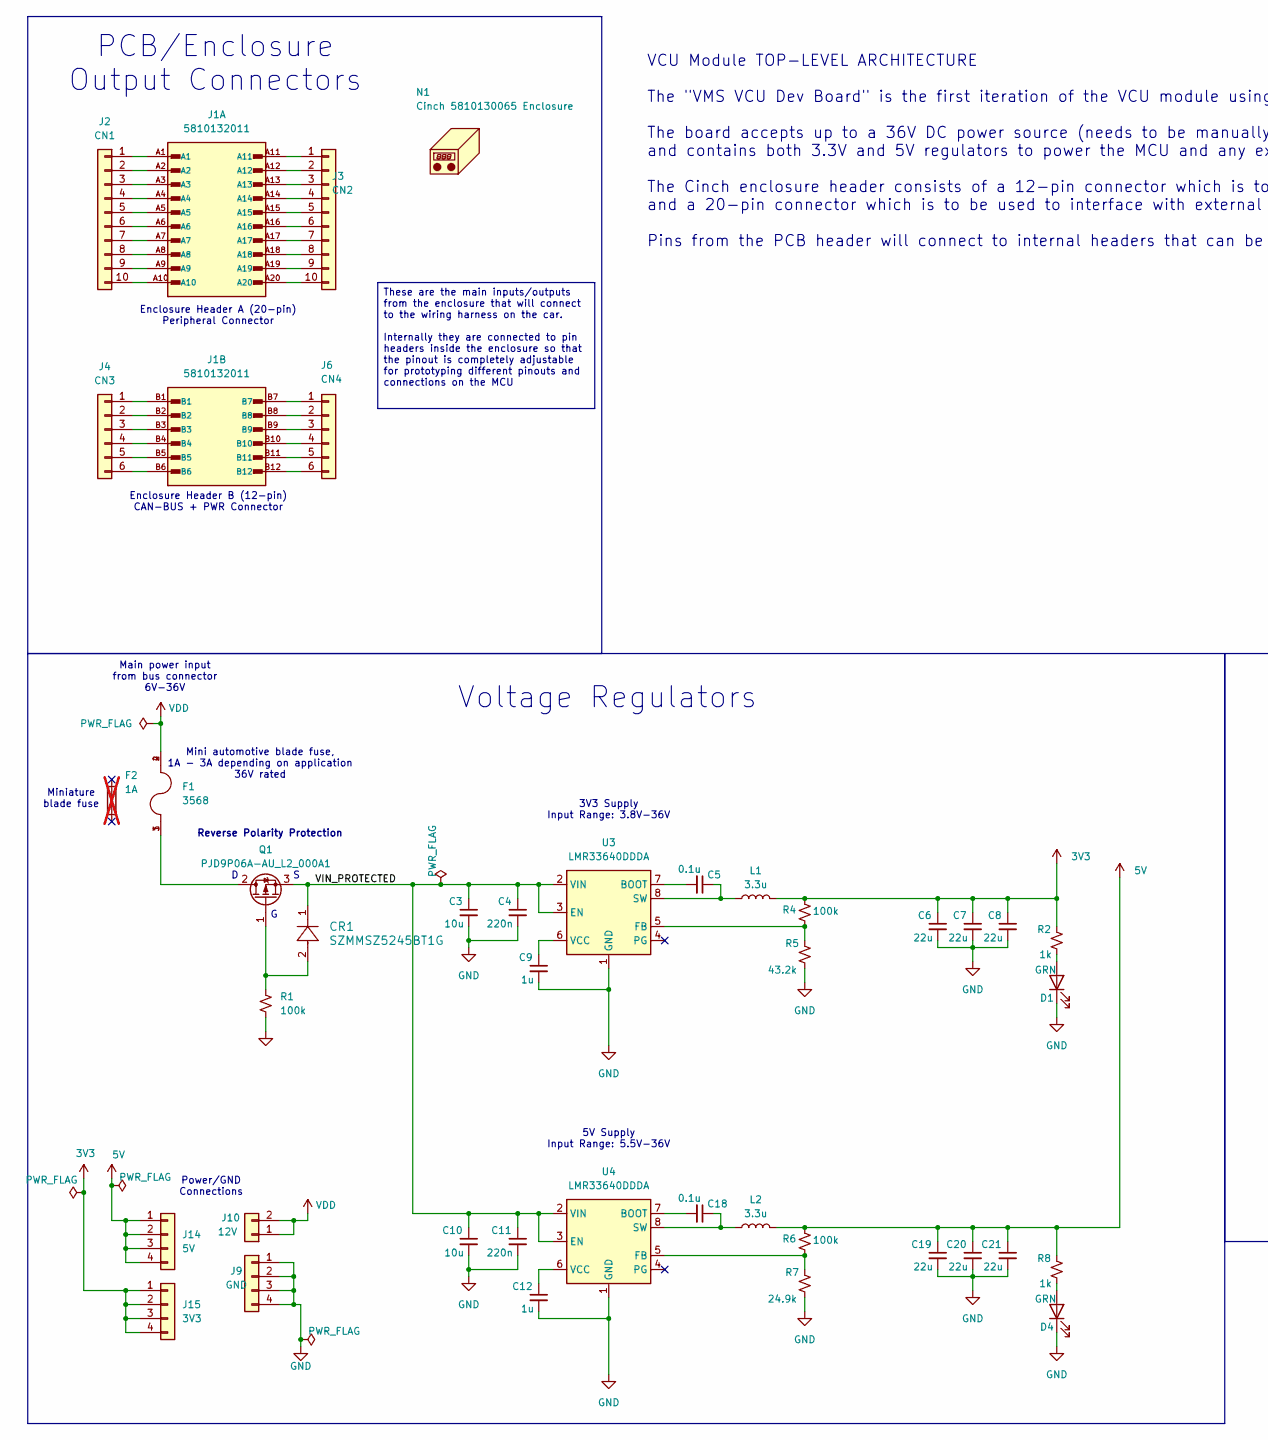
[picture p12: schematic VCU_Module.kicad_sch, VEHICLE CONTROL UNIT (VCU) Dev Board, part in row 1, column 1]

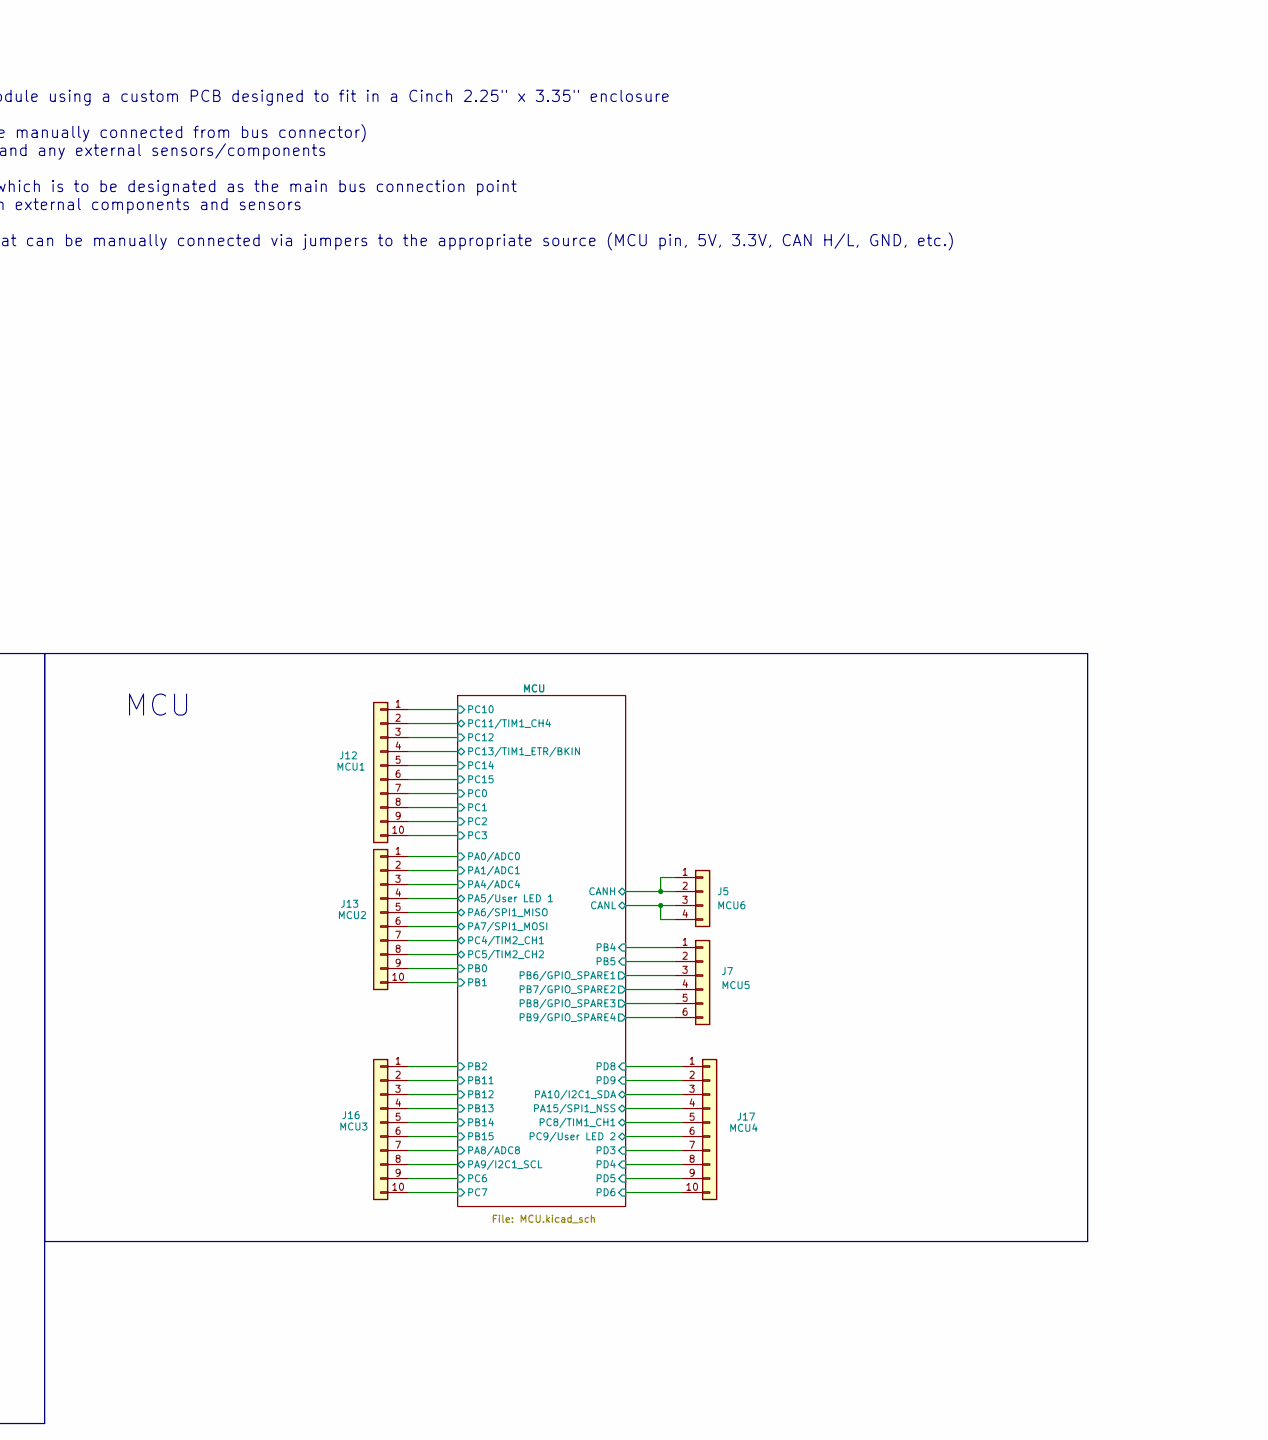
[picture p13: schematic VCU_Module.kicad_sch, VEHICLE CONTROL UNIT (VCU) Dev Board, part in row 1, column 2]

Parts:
C3, C10: 10u; C_0805_2012Metric; MPN GRT21BR61H475KE13L
C4, C11: 220n; C_0805_2012Metric; MPN CL21B224KBFVPNE
C5, C18: 0.1u; C_0805_2012Metric; MPN GCJ21BR72A104KA01L
C6, C7, C8, C19, C20, C21: 22u; C_0805_2012Metric; MPN GRT21BR61C226ME13K
C9, C12: 1u; C_0805_2012Metric; MPN CGA4J3X7S2A105K125AB
CR1: SZMMSZ5245BT1G; SOD123_DIO; MPN SZMMSZ5245BT1G
D1, D4: GRN; LED_0805_2012Metric_Pad1.15x1.40mm_HandSolder; MPN SMLMN2ECTT86C
F1: 3568; FUSE_3568; PARTREV C
F2: 1A; Fuse_Blade_Mini_directSolder; not fitted
J1: 5810132011; Cinch_5810132011_PCB_Header; PARTREV B
J2: CN1; 1x10_Header_f; MPN PPPC101LFBN-RC
J3: CN2; 1x10_Header_f; MPN PPPC101LFBN-RC
J4: CN3; PinHeader_1x06_P2.54mm_Vertical; MPN PPPC061LFBN-RC
J5: MCU6; PinHeader_1x04_P2.54mm_Vertical; MPN PPPC041LFBN-RC
J6: CN4; PinHeader_1x06_P2.54mm_Vertical; MPN PPPC061LFBN-RC
J7: MCU5; PinHeader_1x06_P2.54mm_Vertical; MPN PPPC061LFBN-RC
J9: GND; PinHeader_1x04_P2.54mm_Vertical; MPN PPPC041LFBN-RC
J10: 12V; PinHeader_1x02_P2.54mm_Vertical; MPN PPPC021LFBN-RC
J12: MCU1; 1x10_Header_f; MPN PPPC101LFBN-RC
J13: MCU2; 1x10_Header_f; MPN PPPC101LFBN-RC
J14: 5V; PinHeader_1x04_P2.54mm_Vertical; MPN PPPC041LFBN-RC
J15: 3V3; PinHeader_1x04_P2.54mm_Vertical; MPN PPPC041LFBN-RC
J16: MCU3; 1x10_Header_f; MPN PPPC101LFBN-RC
J17: MCU4; 1x10_Header_f; MPN PPPC101LFBN-RC
L1, L2: 3.3u; L_0805_2012Metric_Pad1.05x1.20mm_HandSolder; MPN AKPB002012103R3MA2
N1: Cinch 5810130065 Enclosure; SIP9_Housing; MPN 5810130065
Q1: PJD9P06A-AU_L2_000A1; TO-252-2; MPN PJD9P06A-AU_L2_000A1
R1, R4, R6: 100k; R_0805_2012Metric; MPN SG73S2ATTD1003F
R2, R8: 1k; R_0805_2012Metric; MPN SG73S2ATTD1001F
R5: 43.2k; R_0805_2012Metric; MPN RK73H2ATTD4322F
R7: 24.9k; R_0805_2012Metric; MPN RK73H2ATTD2492F
U3, U4: LMR33640DDDA; Texas_HSOP-8-1EP_3.9x4.9mm_P1.27mm_ThermalVias; MPN LMR33640DDDAR

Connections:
3V3: C6.1, C7.1, C8.1, J15.1, J15.2, J15.3, J15.4, L1.2, R2.2, R4.2; also elsewhere on the board
5V: C19.1, C20.1, C21.1, J14.1, J14.2, J14.3, J14.4, L2.2, R6.2, R8.2; also elsewhere on the board
/MCU/CANH: J5.1, J5.2; also elsewhere on the board
/MCU/CANL: J5.3, J5.4; also elsewhere on the board
/MCU/PA0/ADC0: J13.1; also elsewhere on the board
/MCU/PA1/ADC1: J13.2; also elsewhere on the board
/MCU/PA4/ADC4: J13.3; also elsewhere on the board
/MCU/PA5/User LED 1: J13.4; also elsewhere on the board
/MCU/PA6/SPI1_MISO: J13.5; also elsewhere on the board
/MCU/PA7/SPI1_MOSI: J13.6; also elsewhere on the board
/MCU/PA8/ADC8: J16.7; also elsewhere on the board
/MCU/PA9/I2C1_SCL: J16.8; also elsewhere on the board
/MCU/PA10/I2C1_SDA: J17.3; also elsewhere on the board
/MCU/PA15/SPI1_NSS: J17.4; also elsewhere on the board
/MCU/PB0: J13.9; also elsewhere on the board
/MCU/PB1: J13.10; also elsewhere on the board
/MCU/PB2: J16.1; also elsewhere on the board
/MCU/PB4: J7.1; also elsewhere on the board
/MCU/PB5: J7.2; also elsewhere on the board
/MCU/PB6/GPIO_SPARE1: J7.3; also elsewhere on the board
/MCU/PB7/GPIO_SPARE2: J7.4; also elsewhere on the board
/MCU/PB8/GPIO_SPARE3: J7.5; also elsewhere on the board
/MCU/PB9/GPIO_SPARE4: J7.6; also elsewhere on the board
/MCU/PB11: J16.2; also elsewhere on the board
/MCU/PB12: J16.3; also elsewhere on the board
/MCU/PB13: J16.4; also elsewhere on the board
/MCU/PB14: J16.5; also elsewhere on the board
/MCU/PB15: J16.6; also elsewhere on the board
/MCU/PC0: J12.7; also elsewhere on the board
/MCU/PC1: J12.8; also elsewhere on the board
/MCU/PC2: J12.9; also elsewhere on the board
/MCU/PC3: J12.10; also elsewhere on the board
/MCU/PC4/TIM2_CH1: J13.7; also elsewhere on the board
/MCU/PC5/TIM2_CH2: J13.8; also elsewhere on the board
/MCU/PC6: J16.9; also elsewhere on the board
/MCU/PC7: J16.10; also elsewhere on the board
/MCU/PC8/TIM1_CH1: J17.5; also elsewhere on the board
/MCU/PC9/User LED 2: J17.6; also elsewhere on the board
/MCU/PC10: J12.1; also elsewhere on the board
/MCU/PC11/TIM1_CH4: J12.2; also elsewhere on the board
/MCU/PC12: J12.3; also elsewhere on the board
/MCU/PC13/TIM1_ETR/BKIN: J12.4; also elsewhere on the board
/MCU/PC14: J12.5; also elsewhere on the board
/MCU/PC15: J12.6; also elsewhere on the board
/MCU/PD3: J17.7; also elsewhere on the board
/MCU/PD4: J17.8; also elsewhere on the board
/MCU/PD5: J17.9; also elsewhere on the board
/MCU/PD6: J17.10; also elsewhere on the board
/MCU/PD8: J17.1; also elsewhere on the board
/MCU/PD9: J17.2; also elsewhere on the board
/VIN_PROTECTED: C3.1, C4.1, C10.1, C11.1, CR1.1, Q1.3 (S), U3.2 (VIN), U3.3 (EN), U4.2 (VIN), U4.3 (EN)
GND: C3.2, C4.2, C6.2, C7.2, C8.2, C9.2, C10.2, C11.2, C12.2, C19.2, C20.2, C21.2, D1.1 (K), D4.1 (K), J9.1, J9.2, J9.3, J9.4, R1.2, R5.1, R7.1, U3.1 (GND), U3.9 (GND), U4.1 (GND), U4.9 (GND); also elsewhere on the board
unnamed: D1.2 (A), R2.1
unnamed: D4.2 (A), R8.1
unnamed: J1.A1, J2.1
unnamed: J1.A2, J2.2
unnamed: J1.A3, J2.3
unnamed: J1.A4, J2.4
unnamed: J1.A5, J2.5
unnamed: J1.A6, J2.6
unnamed: J1.A7, J2.7
unnamed: J1.A8, J2.8
unnamed: J1.A9, J2.9
unnamed: J1.A10, J2.10
unnamed: J1.A11, J3.1
unnamed: J1.A12, J3.2
unnamed: J1.A13, J3.3
unnamed: J1.A14, J3.4
unnamed: J1.A15, J3.5
unnamed: J1.A16, J3.6
unnamed: J1.A17, J3.7
unnamed: J1.A18, J3.8
unnamed: J1.A19, J3.9
unnamed: J1.A20, J3.10
unnamed: J1.B1, J4.1
unnamed: J1.B2, J4.2
unnamed: J1.B3, J4.3
unnamed: J1.B4, J4.4
unnamed: J1.B5, J4.5
unnamed: J1.B6, J4.6
unnamed: J1.B7, J6.1
unnamed: J1.B8, J6.2
unnamed: J1.B9, J6.3
unnamed: J1.B10, J6.4
unnamed: J1.B11, J6.5
unnamed: J1.B12, J6.6
unnamed: F1.1, F1.3, Q1.2 (D)
unnamed: CR1.2, Q1.1 (G), R1.1
unnamed: C5.2, U3.7 (BOOT)
unnamed: R4.1, R5.2, U3.5 (FB)
unnamed: C5.1, L1.1, U3.8 (SW)
unnamed: C9.1, U3.6 (VCC)
unnamed: C18.2, U4.7 (BOOT)
unnamed: R6.1, R7.2, U4.5 (FB)
unnamed: C18.1, L2.1, U4.8 (SW)
unnamed: C12.1, U4.6 (VCC)
VDD: F1.2, F1.4, J10.1, J10.2

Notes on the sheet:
Reverse Polarity Protection
Enclosure Header B (12-pin) CAN-BUS + PWR Connector
5V Supply Input Range: 5.5V-36V
Main power input from bus connector 6V-36V
3V3 Supply Input Range: 3.8V-36V
PCB/Enclosure Output Connectors
MCU
Power/GND Connections
Mini automotive blade fuse, 1A - 3A depending on application 36V rated
Miniature blade fuse
VCU Module TOP-LEVEL ARCHITECTURE The "VMS VCU Dev Board" is the first iteration of the VCU module using a custom PCB designed to fit in a Cinch 2.25" x 3.35" enclosure The board accepts up to a 36V DC power source (needs to be manually connected from bus connector) and contains both 3.3V and 5V re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
Enclosure Header A (20-pin) Peripheral Connector
Voltage Regulators
These are the main inputs/outputs from the enclosure that will connect to the wiring harness on the car. Internally they are connected to pin headers inside the enclosure so that the pinout is completely adjustable for prototyping different pinouts and connections on the MCU

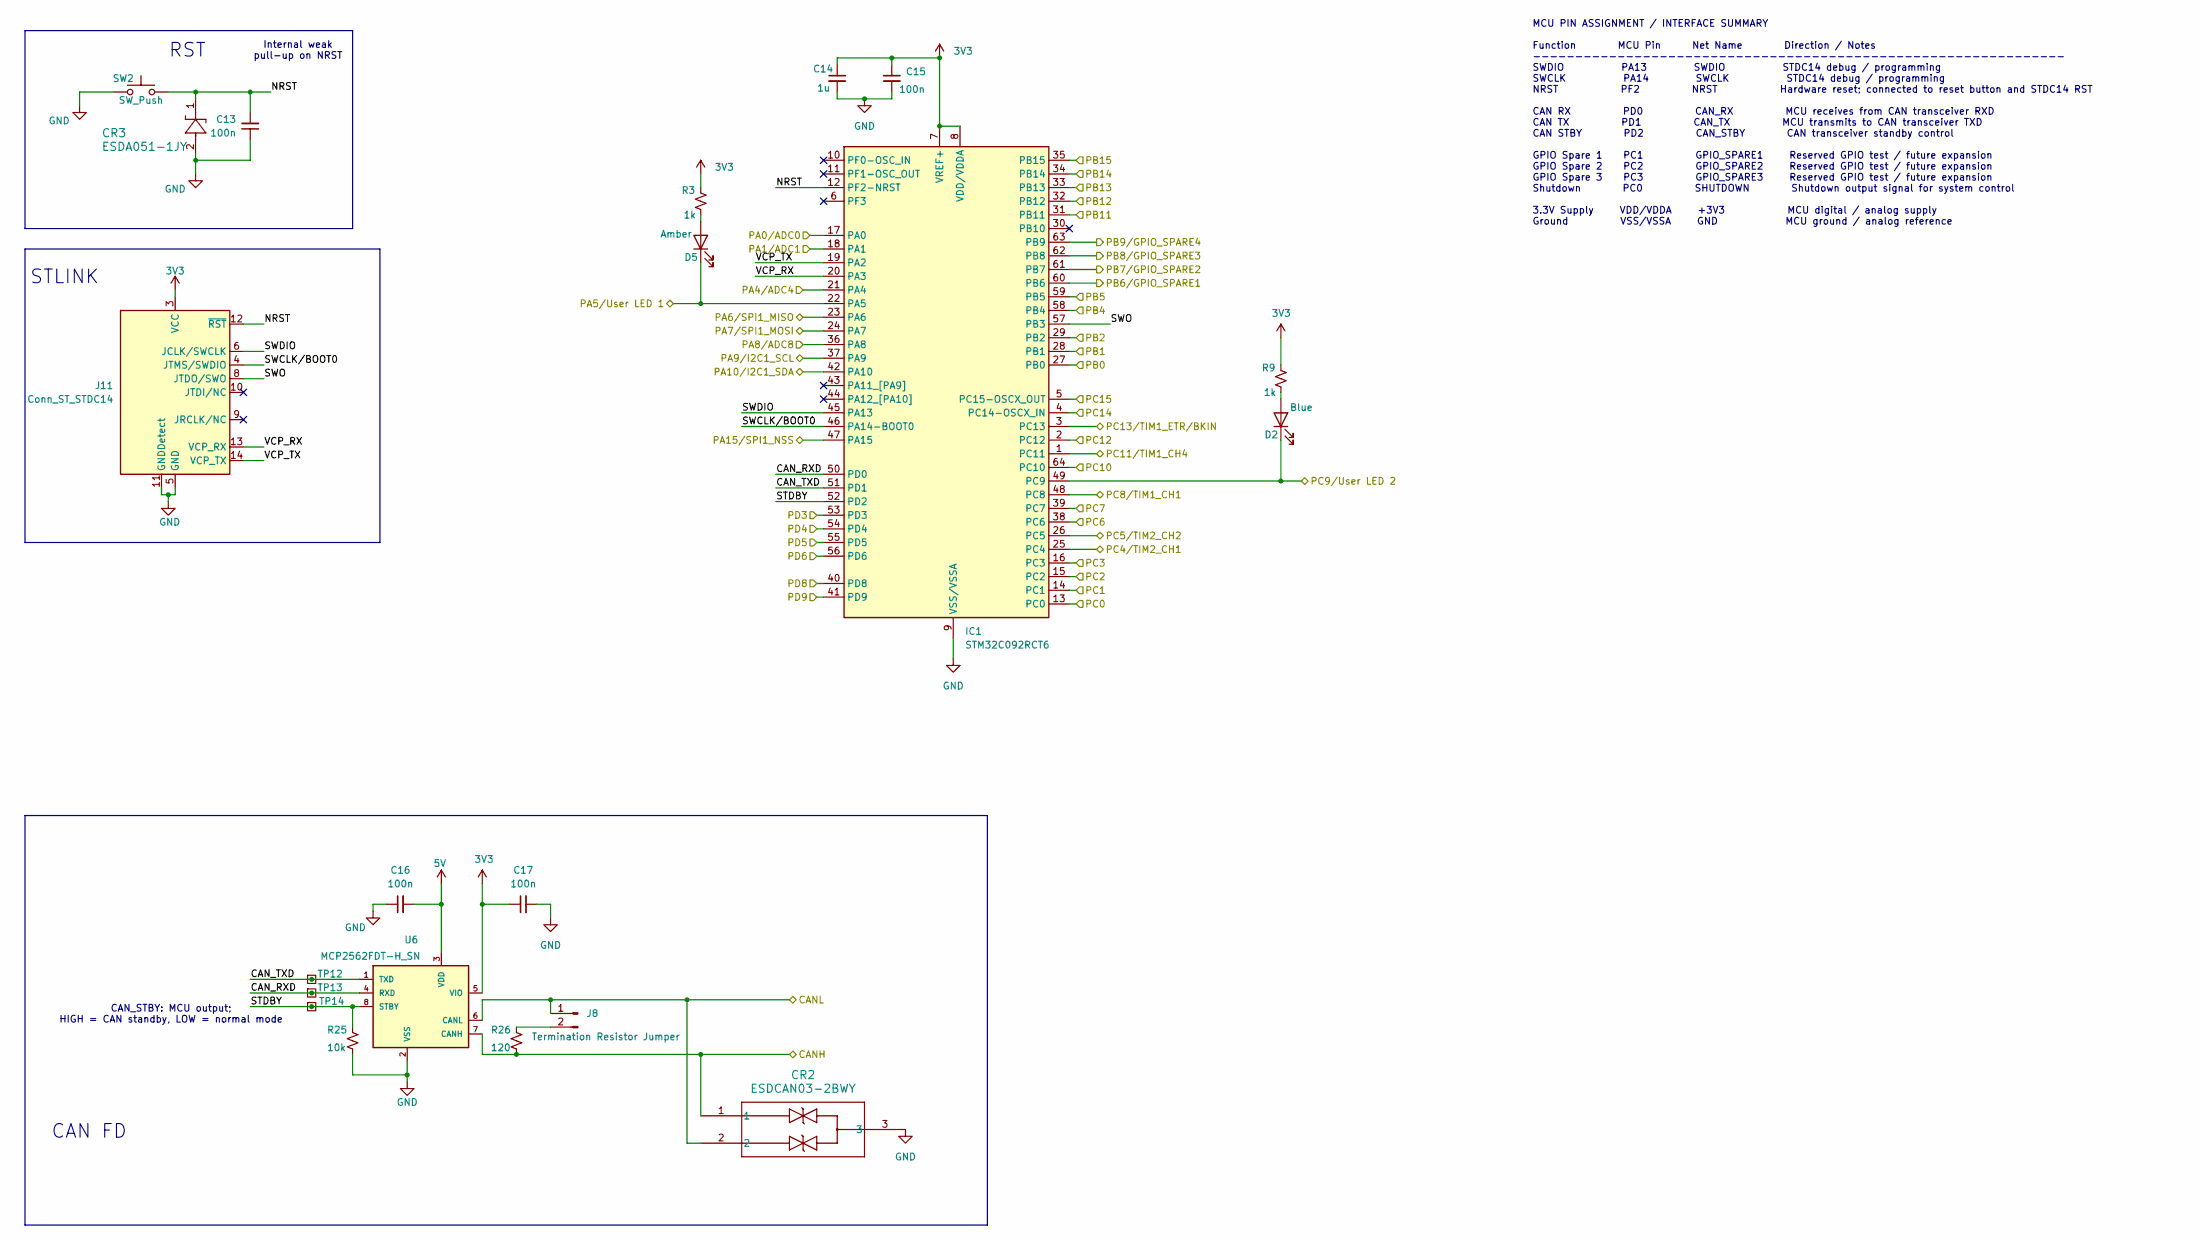
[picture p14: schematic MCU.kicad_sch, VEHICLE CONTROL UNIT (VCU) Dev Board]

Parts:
C13, C15, C16, C17: 100n; C_0805_2012Metric; MPN GCJ21BR72A104KA01L
C14: 1u; C_0805_2012Metric; MPN CGA4J3X7S2A105K125AB
CR2: ESDCAN03-2BWY; SOT323-3L_STM; MPN ESDCAN03-2BWY
CR3: ESDA051-1JY; D_SOD-323; MPN ESDA051-1JY
D2: Blue; LED_0805_2012Metric_Pad1.15x1.40mm_HandSolder; MPN SMLMN2BCTT86C
D5: Amber; LED_0805_2012Metric_Pad1.15x1.40mm_HandSolder; MPN SML-H12D8TT86C
IC1: STM32C092RCT6; QFP50P1200X1200X160-64N; Manufacturer_Part_Number STM32C092RCT6; Mouser Part Number 511-STM32C092RCT6
J8: Termination Resistor Jumper; PinHeader_1x02_P2.54mm_Vertical; MPN TS-102-T-A
J11: Conn_ST_STDC14; PinHeader_2x07_P1.27mm_Vertical; MPN FTSH-107-01-S-D-K
R3, R9: 1k; R_0805_2012Metric; MPN SG73S2ATTD1001F
R25: 10k; R_0805_2012Metric; MPN SG73S2ATTD103J
R26: 120; R_0805_2012Metric; MPN SG73S2ATTD1200F
SW2: SW_Push; SW_PUSH_6mm_H4.3mm; MPN B3F-1000
TP12, TP13, TP14: TestPoint_Small; TestPoint_THTPad_D1.5mm_Drill0.7mm
U6: MCP2562FDT-H_SN; SOIC127P600X175-8N; MPN MCP2562FDT-H/SN

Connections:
3V3: C14.1, C15.1, C17.1, IC1.7 (VREF+), IC1.8 (VDD/VDDA), J11.3 (VCC), R3.2, R9.2, U6.5 (VIO); also elsewhere on the board
5V: C16.2, U6.3 (VDD); also elsewhere on the board
/MCU/CANH: CR2.1, R26.2, U6.7 (CANH); also elsewhere on the board
/MCU/CANL: CR2.2, J8.1, U6.6 (CANL); also elsewhere on the board
/MCU/CAN_RXD: IC1.50 (PD0), TP13.1 (1_1), U6.4 (RXD)
/MCU/CAN_TXD: IC1.51 (PD1), TP12.1 (1_1), U6.1 (TXD)
/MCU/NRST: C13.2, CR3.1, IC1.12 (PF2-NRST), J11.12 (~RST), SW2.1
/MCU/PA0/ADC0: IC1.17 (PA0); also elsewhere on the board
/MCU/PA1/ADC1: IC1.18 (PA1); also elsewhere on the board
/MCU/PA4/ADC4: IC1.21 (PA4); also elsewhere on the board
/MCU/PA5/User LED 1: D5.1 (K), IC1.22 (PA5); also elsewhere on the board
/MCU/PA6/SPI1_MISO: IC1.23 (PA6); also elsewhere on the board
/MCU/PA7/SPI1_MOSI: IC1.24 (PA7); also elsewhere on the board
/MCU/PA8/ADC8: IC1.36 (PA8); also elsewhere on the board
/MCU/PA9/I2C1_SCL: IC1.37 (PA9); also elsewhere on the board
/MCU/PA10/I2C1_SDA: IC1.42 (PA10); also elsewhere on the board
/MCU/PA15/SPI1_NSS: IC1.47 (PA15); also elsewhere on the board
/MCU/PB0: IC1.27 (PB0); also elsewhere on the board
/MCU/PB1: IC1.28 (PB1); also elsewhere on the board
/MCU/PB2: IC1.29 (PB2); also elsewhere on the board
/MCU/PB4: IC1.58 (PB4); also elsewhere on the board
/MCU/PB5: IC1.59 (PB5); also elsewhere on the board
/MCU/PB6/GPIO_SPARE1: IC1.60 (PB6); also elsewhere on the board
/MCU/PB7/GPIO_SPARE2: IC1.61 (PB7); also elsewhere on the board
/MCU/PB8/GPIO_SPARE3: IC1.62 (PB8); also elsewhere on the board
/MCU/PB9/GPIO_SPARE4: IC1.63 (PB9); also elsewhere on the board
/MCU/PB11: IC1.31 (PB11); also elsewhere on the board
/MCU/PB12: IC1.32 (PB12); also elsewhere on the board
/MCU/PB13: IC1.33 (PB13); also elsewhere on the board
/MCU/PB14: IC1.34 (PB14); also elsewhere on the board
/MCU/PB15: IC1.35 (PB15); also elsewhere on the board
/MCU/PC0: IC1.13 (PC0); also elsewhere on the board
/MCU/PC1: IC1.14 (PC1); also elsewhere on the board
/MCU/PC2: IC1.15 (PC2); also elsewhere on the board
/MCU/PC3: IC1.16 (PC3); also elsewhere on the board
/MCU/PC4/TIM2_CH1: IC1.25 (PC4); also elsewhere on the board
/MCU/PC5/TIM2_CH2: IC1.26 (PC5); also elsewhere on the board
/MCU/PC6: IC1.38 (PC6); also elsewhere on the board
/MCU/PC7: IC1.39 (PC7); also elsewhere on the board
/MCU/PC8/TIM1_CH1: IC1.48 (PC8); also elsewhere on the board
/MCU/PC9/User LED 2: D2.1 (K), IC1.49 (PC9); also elsewhere on the board
/MCU/PC10: IC1.64 (PC10); also elsewhere on the board
/MCU/PC11/TIM1_CH4: IC1.1 (PC11); also elsewhere on the board
/MCU/PC12: IC1.2 (PC12); also elsewhere on the board
/MCU/PC13/TIM1_ETR/BKIN: IC1.3 (PC13); also elsewhere on the board
/MCU/PC14: IC1.4 (PC14-OSCX_IN); also elsewhere on the board
/MCU/PC15: IC1.5 (PC15-OSCX_OUT); also elsewhere on the board
/MCU/PD3: IC1.53 (PD3); also elsewhere on the board
/MCU/PD4: IC1.54 (PD4); also elsewhere on the board
/MCU/PD5: IC1.55 (PD5); also elsewhere on the board
/MCU/PD6: IC1.56 (PD6); also elsewhere on the board
/MCU/PD8: IC1.40 (PD8); also elsewhere on the board
/MCU/PD9: IC1.41 (PD9); also elsewhere on the board
/MCU/STDBY: IC1.52 (PD2), R25.1, TP14.1 (1_1), U6.8 (STBY)
/MCU/SWCLK/BOOT0: IC1.46 (PA14-BOOT0), J11.4 (JTMS/SWDIO)
/MCU/SWDIO: IC1.45 (PA13), J11.6 (JCLK/SWCLK)
/MCU/SWO: IC1.57 (PB3), J11.8 (JTDO/SWO)
/MCU/VCP_RX: IC1.20 (PA3), J11.13 (VCP_RX)
/MCU/VCP_TX: IC1.19 (PA2), J11.14 (VCP_TX)
GND: C13.1, C14.2, C15.2, C16.1, C17.2, CR2.3, CR3.2, IC1.9 (VSS/VSSA), J11.5 (GND), J11.7 (GND), J11.11 (GNDDetect), R25.2, SW2.2, U6.2 (VSS); also elsewhere on the board
unnamed: D2.2 (A), R9.1
unnamed: D5.2 (A), R3.1
unnamed: J8.2, R26.1

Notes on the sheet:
MCU PIN ASSIGNMENT / INTERFACE SUMMARY Function MCU Pin Net Name Direction / Notes --------------------------------------------------------------- SWDIO PA13 SWDIO STDC14 debug / programming SWCLK PA14 SWCLK STDC14 debug / programming NRST PF2 NRST Hardware reset; connected to reset button and STDC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
STLINK
CAN FD
RST
CAN_STBY: MCU output; HIGH = CAN standby, LOW = normal mode
Internal weak pull-up on NRST

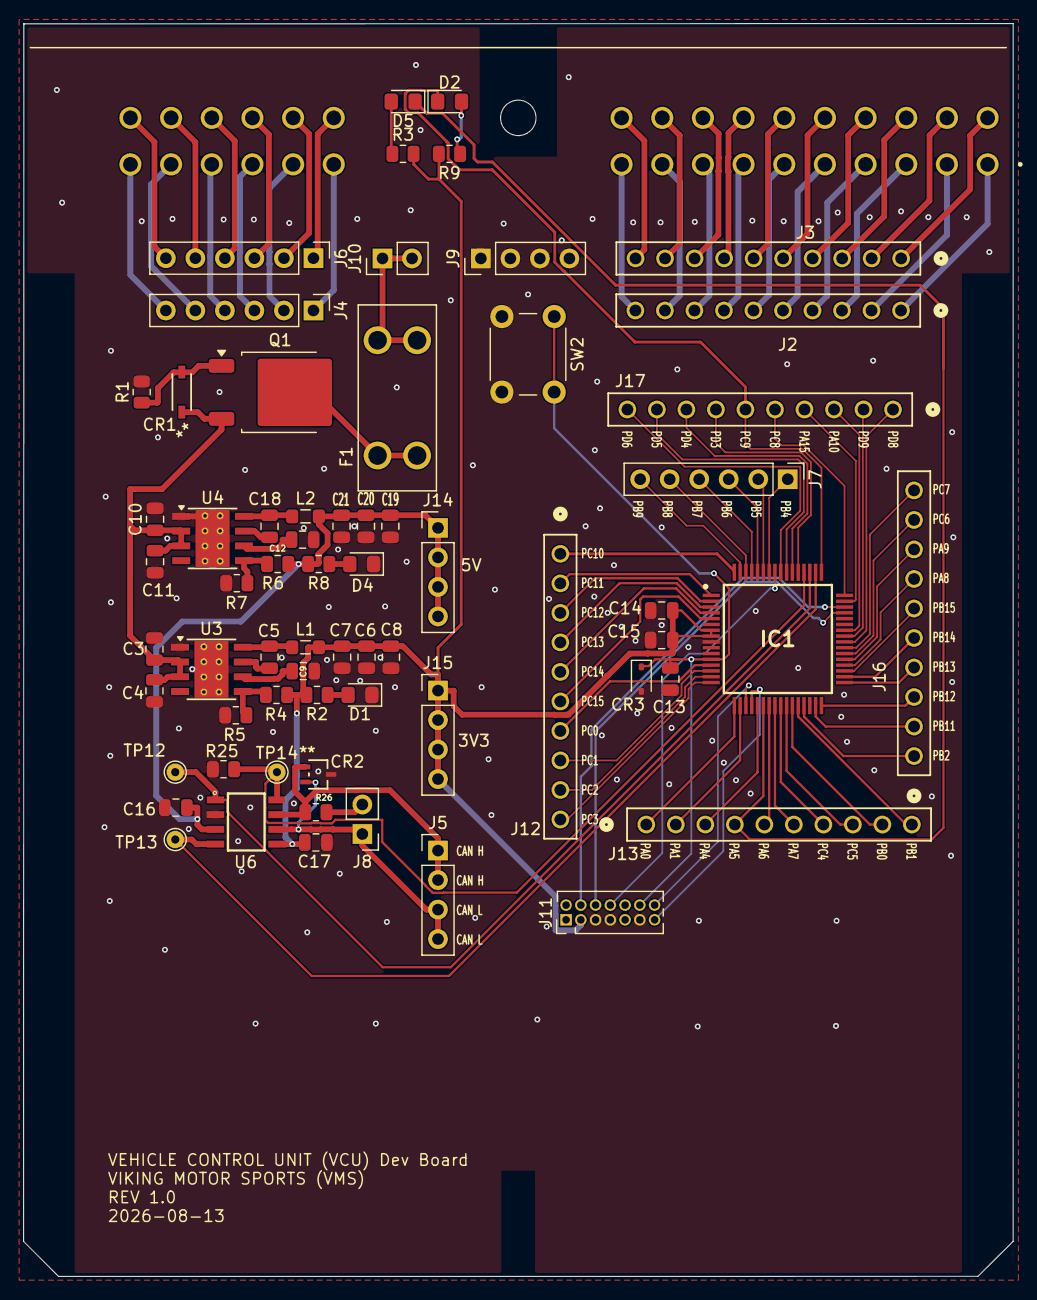
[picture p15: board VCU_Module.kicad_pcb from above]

Board: 2 copper layers, 85.2 x 107.8 mm, 66 parts (0 on the bottom side), 109 nets.

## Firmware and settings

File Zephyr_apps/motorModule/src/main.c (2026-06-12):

/*
 * Main application for the VCU (Vehicle Control Unit) module.
 *
 * This application demonstrates a modular embedded software architecture
 * using the Zephyr RTOS. The system currently performs:
 *
 *  - accelerator pedal ADC acquisition
 *  - PWM motor control
 *  - CAN bus initialization
 *  - CAN message transmission
 *  - CAN message reception using a dedicated thread
 *
 * System Overview:
 *
 *   pedal_adc module
 *        ↓
 *   main control loop
 *        ↓
 *   motor_controller_pwm module
 *        ↓
 *   can_sender module
 *
 * Meanwhile:
 *
 *   can_receiver module
 *        ↓
 *   background CAN receive thread
 *
 * The main loop continuously:
 *  1. reads accelerator pedal position
 *  2. applies pedal deadband logic
 *  3. calculates PWM duty cycle
 *  4. drives the motor controller
 *  5. transmits pedal position over CAN
 */

#include <stdio.h>
#include <stdint.h>
#include <stdlib.h>

#include <zephyr/device.h>
#include <zephyr/kernel.h>
#include <zephyr/sys/printk.h>

#include "pedal_adc.h"
#include "motor_controller_pwm.h"
#include "can_interface.h"
#include "can_receiver.h"
#include "can_sender.h"
#include "can_database.h"

/*
 * Main control loop execution period in milliseconds.
 *
 * This determines how frequently:
 *  - ADC values are sampled
 *  - motor outputs are updated
 *  - CAN messages are transmitted
 */
#define LOOP_PERIOD_MS 33


/*
 * Main application entry point.
 *
 * This function performs:
 *  - subsystem initialization
 *  - CAN interface startup
 *  - CAN receiver thread creation
 *  - continuous vehicle control execution
 *
 * Returns:
 *   0  -> normal operation (typically never reached)
 *  <0  -> initialization failure
 */
int main(void)
{
	static int rc;
	int loop_ctr = 0;
	pedal_data_t pedals;
	pedals.acc_pedal = 0;
	pedals.brake_pedal = 0;
	/*
	 * Retrieve pointer to initialized CAN controller device.
	 *
	 * The CAN hardware itself is owned by the CAN interface
	 * module and accessed through this helper function.
	 */
	const struct device *can_dev =
		can_interface_get_device();

	/* ---------- Subsystem Initialization ---------- */
	/*
	 * Initialize PWM motor controller subsystem.
	 */
	rc = motor_pwm_setup();
	if (rc) {
		printk("motor_pwm_setup failed: %d\n", rc);
		return rc;
	}

	/*
	 * Initialize CAN controller hardware.
	 */
	rc = can_interface_init(can_dev);
	if (rc) {
		printk("can_interface_init failed: %d\n", rc);
		return rc;
	}

	/*
	 * Create and start background CAN receive thread.
	 */
	rc = rx_thread_create(can_dev, (void *)&pedals);
	if (rc) {
		printk("rx_thread_create failed: %d\n", rc);
		return rc;
	}

	printf("Finished init.\n");

	/* ---------- Main Vehicle Control Loop ---------- */

	while (1) {
		/* ---------- Motor Control ---------- */
		// * Motor direction command
		motor_dir dir = DIR_FORWARD;
		motor_side side = BOTH;
		float duty = pedals.acc_pedal;

		if (pedals.brake_pedal) {
			dir = DIR_STOP;
			duty = pedals.brake_pedal;
		}
		else if (pedals.acc_pedal) {
			dir = DIR_FORWARD;
			duty = pedals.acc_pedal;
		}
		else {
			dir = DIR_COAST;
			duty = 0;
		}

		// * Apply motor direction command.
		(void)set_direction(dir, side);

		// * Apply PWM duty cycle command.
		(void)set_speed(duty, side);

		

		if (can_send_sensor_data(can_dev, (uint16_t)duty, MOTOR_DUTY_MSG_ID)) {
			printk("can_send_sensor_data failed: %d\n", rc);
		}

		if ((loop_ctr % 100) == 0) {
			printf("main loop: duty=%d\npedals.acc_pedal=%d\npedals.brake_pedal=%d\nmotor_dir=%s\n",
				(uint16_t)duty,
				pedals.acc_pedal,
				pedals.acc_pedal,
				(dir==DIR_FORWARD) ? "DIR_FORWARD" : 
				(dir==DIR_REVERSE) ? "DIR_REVERSE" : 
				(dir==DIR_STOP) ? "DIR_STOP" : 
				(dir==DIR_COAST) ? "DIR_COAST" : "UNKNOWN");
		}
		loop_ctr++;
		// * Wait until next control loop iteration.
		k_msleep(LOOP_PERIOD_MS);
	}
};

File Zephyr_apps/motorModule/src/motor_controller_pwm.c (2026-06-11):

/*
 * motor_controller_pwm.c
 *
 * PWM motor controller implementation for the VCU module.
 *
 * This module controls a DC motor driver using:
 *
 *  - PWM output for speed control
 *  - Two GPIO outputs for direction control
 *
 * Hardware configuration is obtained from the Zephyr
 * devicetree using the zephyr_user node.
 *
 * Direction control:
 *     IN1 = 1, IN2 = 0 -> Forward
 *     IN1 = 0, IN2 = 1 -> Reverse
 *     IN1 = 0, IN2 = 0 -> Coast/Stop
 *
 * PWM control:
 *     The PWM duty cycle determines average motor voltage
 *     and therefore motor speed.
 */

#include "motor_controller_pwm.h"

#include <zephyr/drivers/gpio.h>
#include <zephyr/drivers/pwm.h>
#include <zephyr/kernel.h>

/*
 * Obtain the zephyr_user devicetree node.
 *
 * This node contains all application-specific
 * hardware mappings.
 */
#ifndef ZEPHYR_USER
#define ZEPHYR_USER DT_PATH(zephyr_user)
#endif

/*
 * PWM specification for the motor enable pin.
 *
 * This structure contains:
 *  - PWM controller device
 *  - PWM channel
 *  - PWM period
 *  - PWM flags
 */
static const struct pwm_dt_spec pwmLeft = PWM_DT_SPEC_GET_BY_IDX(ZEPHYR_USER, 0);
static const struct pwm_dt_spec pwmRight = PWM_DT_SPEC_GET_BY_IDX(ZEPHYR_USER, 1);

/*
 * GPIO specification for motor direction pins
 */
static const struct gpio_dt_spec leftA = GPIO_DT_SPEC_GET(ZEPHYR_USER, in1_gpios);
static const struct gpio_dt_spec leftB = GPIO_DT_SPEC_GET(ZEPHYR_USER, in2_gpios);
static const struct gpio_dt_spec righta = GPIO_DT_SPEC_GET(ZEPHYR_USER, in3_gpios);
static const struct gpio_dt_spec rightb = GPIO_DT_SPEC_GET(ZEPHYR_USER, in4_gpios);

/*
 * Shared return code variable used throughout
 * the module for hardware API calls.
 */
static int rc;

/*
 * Initialize motor PWM and GPIO hardware.
 *
 * This function must be called before
 * attempting to control the motor.
 *
 * Initialization sequence:
 *  1. Verify PWM device readiness
 *  2. Verify GPIO readiness
 *  3. Configure GPIO pins as outputs
 *  4. Stop the motor
 *  5. Set PWM duty cycle to 0%
 *
 * Returns:
 *     0 on success.
 *     Negative Zephyr error code on failure.
 */
int motor_pwm_setup(void)
{
	/* Verify PWM hardware is ready */
	if (!pwm_is_ready_dt(&pwmLeft) ||
		!pwm_is_ready_dt(&pwmRight)) {
		
		printf("PWM not ready\n");
		return -ENODEV;
	}

	/* Verify GPIO hardware is ready */
	if (!gpio_is_ready_dt(&leftA) ||
	    !gpio_is_ready_dt(&leftB) ||
		!gpio_is_ready_dt(&righta) ||
		!gpio_is_ready_dt(&rightb)) {

		printf("Direction GPIOs not ready\n");
		return -ENODEV;
	}

	/* Configure IN1 as output */
	if (((rc = gpio_pin_configure_dt(&leftA, GPIO_OUTPUT_INACTIVE)) != 0) ||
		((rc = gpio_pin_configure_dt(&leftB, GPIO_OUTPUT_INACTIVE)) != 0) ||
		((rc = gpio_pin_configure_dt(&righta, GPIO_OUTPUT_INACTIVE)) != 0) ||
		((rc = gpio_pin_configure_dt(&rightb, GPIO_OUTPUT_INACTIVE)) != 0)) {
		printf("gpio_pin_configure_dt failed: %d\n", rc);
		return rc;
	}

	printf("Motor initialized successfully\n");


	/*
	 * Ensure the motor starts in a safe state.
	 */
	motor_side side = BOTH;

	(void)set_direction(DIR_STOP, side);

	/*
	 * Set PWM duty cycle to 0%.
	 */
	(void)pwm_set_pulse_dt(&pwmLeft, 0);

	(void)pwm_set_pulse_dt(&pwmRight, 0);

	return 0;
};

/*
 * Set the motor direction.
 *
 * Depending on the selected direction, the GPIO
 * direction pins are driven appropriately.
 *
 * Forward:
 *     IN1 = HIGH
 *     IN2 = LOW
 *
 * Reverse:
 *     IN1 = LOW
 *     IN2 = HIGH
 *
 * Stop:
 *     IN1 = LOW
 *     IN2 = LOW
 *
 * Parameters:
 *     d - Desired motor direction.
 *
 * Returns:
 *     0 on success.
 *     Negative Zephyr error code on failure.
 */
int set_direction(motor_dir d, motor_side side)
{
	int a = 0, b = 0;

	switch (d) {
		case DIR_STOP:
			a = 1;
			b = 1;
			break;
		case DIR_COAST:
			a = 0;
			b = 0;
			break;
		case DIR_FORWARD:
			a = 1;
			b = 0;
			break;
		case DIR_REVERSE:
			a = 0;
			b = 1;
			break;
	}

	if (side == LEFT){
		if (((rc = gpio_pin_set_dt(&leftA, a)) != 0) ||
				((rc = gpio_pin_set_dt(&leftB, b)) != 0) ) {
					return rc;
				}
	}
	else if (side == RIGHT){
		if (((rc = gpio_pin_set_dt(&righta, a)) != 0) ||
				((rc = gpio_pin_set_dt(&rightb, b)) != 0) ) {
					return rc;
				}
	}
	else{
		if (((rc = gpio_pin_set_dt(&leftA, a)) != 0) ||
				((rc = gpio_pin_set_dt(&leftB, b)) != 0) ||
				((rc = gpio_pin_set_dt(&righta, a)) != 0) ||
				((rc = gpio_pin_set_dt(&rightb, b)) != 0) ) {
					return rc;
				}
	}

	return 0;
};

/*
 * Set motor speed using PWM duty cycle.
 *
 * The PWM duty cycle determines how long the PWM
 * signal remains active during each period.
 *
 * 0%  -> motor off
 * 100% -> full speed
 *
 * The duty cycle is automatically clamped
 * to the valid range.
 *
 * Parameters:
 *     duty_cycle - Desired duty cycle percentage.
 *
 * Returns:
 *     0 on success.
 *     Negative Zephyr error code on failure.
 */
int set_speed(float duty_cycle, motor_side side)
{
	/* Clamp duty cycle to valid range */
	if (duty_cycle < 0.0f) {
		duty_cycle = 0.0f;

	} else if (duty_cycle > 100.0f) {
		duty_cycle = 100.0f;
	}

	/*
	 * Convert duty cycle percentage into
	 * PWM pulse width in nanoseconds.
	 */
	uint64_t pulse =
		(uint64_t)((duty_cycle / 100.0f) * pwmLeft.period);
	
	/*
	 * Apply PWM pulse width to hardware.
	 */
	if (side == LEFT) return pwm_set_pulse_dt(&pwmLeft, (uint32_t)pulse);
	else if (side == RIGHT) return pwm_set_pulse_dt(&pwmRight, (uint32_t)pulse);
	else {
		int rc = 0;
		if (((rc = pwm_set_pulse_dt(&pwmLeft, (uint32_t)pulse)) != 0) ||
			((rc = pwm_set_pulse_dt(&pwmLeft, (uint32_t)pulse)) != 0) ) {
				return rc;
			}
		else return 0;
	}
	
};

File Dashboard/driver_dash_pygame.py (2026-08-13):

"""
                Formula E Driver Dashboard  —  pygame edition
    Smooth 60 fps rendering using hardware-accelerated surfaces.
    Drop-in replacement for the matplotlib version.

    Install:   pip install pygame
    Run:       driver_dash_pygame.py

    Controls:
        W / Up Arrow    – Throttle
        S / Down Arrow  – Brake
        D               – Toggle DRS
        1               – Normal mode
        2               – Attack mode  (uses one zone token)
        3               – Regen+ mode
        4               – Fan Boost mode
        Q / Escape      – Quit

    Serial (hardware):
        In order to use with actual hardware, uncomment the SERIAL SETUP section and set your COM port.
        The dashboard expects simple ASCII commands sent over serial, for example:
            'W' to indicate throttle is pressed
            'B' to indicate brake is pressed
            'D' to toggle DRS
            'U' to activate Attack mode
            'R' to activate Regen+ mode
            'N' to return to Normal mode
            'F' to activate Fan Boost mode
            'X' to quit the application
    @author : Allen Paul
    @date   : 2026
    @file   : driver_dash_pygame.py
"""

import pygame
import pygame.gfxdraw
import math
import time
import random
import sys
import can
import threading
import queue
import json
import paho.mqtt.client as mqtt

# MQTT Configuration
BROKER = "localhost"   # e.g. "test.mosquitto.org" 
PORT = 1883
TOPIC = "pedal"
CLIENT_ID = "publisher_001"

# Callback when connected
def on_connect(client, userdata, flags, rc):
    if rc == 0:
        print("Connected to broker")
    else:
        print(f"Connection failed with code {rc}")

# Callback when message is published
def on_publish(client, userdata, mid):
    print(f"Message {mid} published")

# Create client
client = mqtt.Client(client_id=CLIENT_ID)

client.on_connect = on_connect
client.on_publish = on_publish

# Connect to broker
client.connect(BROKER, PORT, keepalive=60)

# Start network loop
client.loop_start()


# ─────────────────────────────────────────────────────────────────────────────
#  CAN INPUT SETUP
# ─────────────────────────────────────────────────────────────────────────────
BRAKE_MSG_ID = 0x008
ACCELERATOR_MSG_ID = 0x080


#can_bus queue for receiving CAN messages from a separate thread
can_buffer = queue.Queue(maxsize=1000)

# Initialize CAN bus (Linux SocketCAN example, adjust for your platform and CAN interface)
bus = can.interface.Bus(bustype='socketcan', channel='can0', bitrate=500000)
# Below is for testing
#bus = can.interface.Bus(interface='virtual', channel='test', bitrate=500000)


def can_listener():
    while True:  # Added loop to keep thread alive
        try:
            msg = bus.recv(timeout=1.0) # Added timeout to allow clean exit if needed
            if msg:
#                print(f"Listener_Thread: Received CAN message: {msg}")
                can_buffer.put(msg, block=False)
        except queue.Full:
            continue 
        except Exception as e:
            print(f"CAN Error: {e}")
            break

def get_can_message():
    try:
        return can_buffer.get_nowait() # Do not block the UI thread
    except queue.Empty:
        return None

#start CAN listener thread
listener_thread = threading.Thread(target=can_listener, daemon=True)
listener_thread.start()

# ─────────────────────────────────────────────────────────────────────────────
#  SERIAL SETUP  (uncomment to use hardware)
# ─────────────────────────────────────────────────────────────────────────────
# import serial
# try:
#     port = serial.Serial('COM3', 115200, timeout=0)
# except Exception as e:
#     print(f"Serial Error: {e}")
#     port = None
port = None

# ─────────────────────────────────────────────────────────────────────────────
#  CONSTANTS
# ─────────────────────────────────────────────────────────────────────────────
FPS          = 60
MAX_POWER    = 350
MAX_REGEN    = 250
MAX_SPEED    = 290
BAT_CAPACITY = 25.0
DRAG         = 0.00005
BRAKE_FORCE  = 3.0
ACCEL_POWER  = 14.0
MOTOR_WARN, MOTOR_CRIT = 90,  120
BAT_WARN,   BAT_CRIT   = 42,   55
INV_WARN,   INV_CRIT   = 70,   90

# ─────────────────────────────────────────────────────────────────────────────
#  COLORS  (RGB)
# ─────────────────────────────────────────────────────────────────────────────
C = {
    'bg':        (5,   5,   5),
    'card':      (13,  13,  13),
    'border':    (26,  26,  26),
    'green':     (57,  255, 20),
    'orange':    (255, 107, 0),
    'red':       (255, 34,  0),
    'blue':      (0,   170, 255),
    'yellow':    (232, 255, 0),
    'white':     (255, 255, 255),
    'dim':       (51,  51,  51),
    'very_dim':  (20,  20,  20),
    'text_dim':  (250, 250,  250),
    'topbar':    (8,   8,   8),
}

MODE_COLORS = {
    'normal': ((51,  51,  51),  (255, 255, 255)),
    'attack': ((255, 107, 0),   (0,   0,   0)),
    'regen':  ((0,   170, 255), (0,   0,   0)),
    'fan':    ((232, 255, 0),   (0,   0,   0)),
}

def temp_color(val, warn, crit):
    if val > crit * 0.9: return C['red']
    if val > warn:        return C['orange']
    return C['green']

def bat_color(pct):
    if pct < 15: return C['red']
    if pct < 30: return C['orange']
    return C['green']

# ─────────────────────────────────────────────────────────────────────────────
#  VEHICLE STATE
# ─────────────────────────────────────────────────────────────────────────────
state = {
    'velocity':        0.0,
    'accel':           0.0,
    'brake':           0.0,
    'bat_kwh':         BAT_CAPACITY * 0.78,
    'motor_temp':      42.0,
    'bat_temp':        31.0,
    'inv_temp':        38.0,
    'regen_harvested': 0.0,
    'energy_used':     6.1,
    'dist_km':         0.0,
    'lap_secs':        83.471,
    'lap_num':         3,
    'gap_ahead':       1.2,
    'attack_zones':    2,
    'attack_timer':    0,
    'mode':            'normal',
    'drs_active':      False,
    'frame':           0,
    'deploy_kw':       0,
    'regen_kw':        0,
}

def set_mode(m):
    s = state
    if m == 'attack' and s['attack_zones'] > 0:
        s['attack_zones'] -= 1
        s['attack_timer']  = FPS * 3   # 3 seconds of attack mode flash
    s['mode'] = m

# ─────────────────────────────────────────────────────────────────────────────
#  PHYSICS
# ─────────────────────────────────────────────────────────────────────────────
_last_phys = time.perf_counter()
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

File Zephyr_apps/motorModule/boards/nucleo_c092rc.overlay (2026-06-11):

/*
 * Overlay for nucleo_c092rc:
 *  A0  -> PA0  -> ADC1 channel 0  (accelerator potentiometer)
 *	A1  -> PA1  -> ADC1 channel 1  (brake potentiometer)
 *  
 *	D7  -> PA8  -> TIM1_CH1 		(PWM1)
 *  D6	-> PC8	-> B
 *	D5	-> PB4	-> A
 *	
 *	D8  -> PA9  -> TIM1_CH2        (PWM2)
 *	D9	-> PB3	-> a
 *	D10	-> PA15	-> b
 */

/ {
    zephyr,user {
        io-channels = 	<&adc1 0>, <&adc1 1>;

        pwms =
			<&pwm1 1 PWM_USEC(50) PWM_POLARITY_NORMAL>,
			<&pwm1 2 PWM_USEC(50) PWM_POLARITY_NORMAL>;

		in1-gpios = <&gpiob 4 GPIO_ACTIVE_HIGH>;
		in2-gpios = <&gpioc 8 GPIO_ACTIVE_HIGH>;
		in3-gpios = <&gpiob 3 GPIO_ACTIVE_HIGH>;
		in4-gpios = <&gpioa 15 GPIO_ACTIVE_HIGH>;
    };
};

&adc1 {
	#address-cells = <1>;
	#size-cells = <0>;
	status = "okay";

	channel@0 {
		reg = <0>;
		zephyr,gain = "ADC_GAIN_1";
		zephyr,reference = "ADC_REF_INTERNAL";
		zephyr,acquisition-time = <ADC_ACQ_TIME_DEFAULT>;
		zephyr,resolution = <12>;
	};

	channel@1 {
		reg = <1>;
		zephyr,gain = "ADC_GAIN_1";
		zephyr,reference = "ADC_REF_INTERNAL";
		zephyr,acquisition-time = <ADC_ACQ_TIME_DEFAULT>;
		zephyr,resolution = <12>;
	};
};

/*
 * TIM1:
 *   CH1 -> PA8  (D7)
 *   CH2 -> PA9  (D8)
 */
&timers1 {
	status = "okay";
	st,prescaler = <0>;

	pwm1: pwm {
		status = "okay";

		pinctrl-0 = <
			&tim1_ch1_pa8
			&tim1_ch2_pa9
		>;

		pinctrl-names = "default";
	};
};

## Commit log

2026-03-21 adding sample files
2026-03-23 script for finding COM port of board and conncecting to serial port through putty
2026-03-24 added adc_dt sample along with appropriate overlay for c092 board
2026-03-27 created adc/can combo app
2026-03-27 Steering Wheel Code
    This is the framework for the steering wheel sensor. At the moment, it is a potentiometer-based prototype.
2026-03-27 Steering Wheel Code
    Prelim. code for steering wheel using a potentiometer as a prototype.
2026-03-30 added code for adc input to change LED speed
2026-03-31 Simple Display Module for Driver
    This is a preliminary test for the driver display.
2026-04-10 Driver Display via Serial
    Driver display that takes in serial input.
2026-04-27 Claude Generated ADC to PWM (H Bridge) Code This is demo code using Claude, Will add CAN to it later. Needs to be tested, is able to be built
2026-04-27 Change Acquisition time to ticks not time for ADC Claude had it set to time, but Zephyr works mostly in ticks from what I skimmed
2026-04-28 integrating CAN_RECEIVER and driver display
2026-04-28 add bitrate and samplepoint configuration
2026-04-28 socketCAN auto config + pythoncan script
2026-04-29 integrating pedal sensor code with can code
2026-04-30 fixed pedal module deadzone
    [main.c]
2026-05-01 Fixed Accelorator Stall after around 50% accelerator
    [main.c]
2026-05-01 Changes To driver dash for Linux Laptop
2026-05-13 added motor duty CAN message ID
2026-05-15 added candlelight socketCAN firmware
2026-05-17 IBT-2 H-bridge with dual pwm inputs
2026-05-20 Cleaned up comments and code Added can_database.h for defining message IDs and documentation Added struct arrays for CAN filters and frames for easier addition of new messages Flashed to board and up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
2026-05-29 Added driver_dash_pyqt.py to repo
2026-05-29 Added header for PyQt Driver Display
2026-06-08 updated VCUmodule to have brake and accelerator pedal, copied driver dash file to have a copy without the mqtt stuff
2026-06-08 running driver dash with no pit display
2026-06-10 adding CAN to driver dash QT
2026-06-11 updating motor controller code
2026-06-11 motor controller
2026-06-11 added data recieving from can to motor controller
2026-06-12 Adding MqTT to driver_no_display and Python services
2026-06-12 Update comments and print statements for clarity
2026-06-12 updated motor controller to handle direction and duty based on pedal inputs
2026-06-26 added kicad files
    [MCU.kicad_sch, POWER.kicad_sch, VCU_Module.kicad_pcb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]
2026-07-02 added peripherals to mcu
    [MCU.kicad_sch, VCU_Module.kicad_pcb, VCU_Module.kicad_sch]
2026-07-02 added peripherals
    [MCU.kicad_sch, POWER.kicad_sch, VCU_Module.kicad_sch]
2026-07-02 fix broken schematic
    [MCU.kicad_sch, VCU_Module.kicad_sch]
2026-07-03 added peripheral pins with the most functionality based on stm32c092rc datasheet, started placing components and routing traces on pcb
    [MCU.kicad_sch, VCU_Module.kicad_pcb, VCU_Module.kicad_sch]
2026-07-06 placed pcb components, ran traces, still need to fix erc errors
    [VCU_Module.kicad_pcb, freerouting.dsn, temp-freerouting.dsn]
2026-07-07 comments from andrew
    [POWER.kicad_sch, VCU_Module.kicad_sch]
2026-07-09 adding 'devkit' headers to make connections sustomizable inside of the enclosure
    [MCU.kicad_sch, VCU_Module.kicad_pcb, VCU_Module.kicad_sch]
2026-07-09 added switching power supply component
2026-07-11 added new power supply components, new power supply circuitry needs finishing
    [MCU.kicad_sch, VCU_Module.kicad_sch]
2026-07-11 add kicad '.history' to gitignore
2026-07-13 finished reworking power supply with new LMR regulators, reorganized schematic, added description to top page, added user leds with identical layout to the nucleo c092 schematic
    [MCU.kicad_sch, VCU_Module.kicad_sch]
2026-07-13 updated gitignore appropriately for kicad files
2026-07-20 fixed all socket header connections, placed and routed every component on PCB, added all 3d models to footprints
    [MCU.kicad_sch, VCU_Module.kicad_pcb, VCU_Module.kicad_sch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]
2026-07-20 added CAD files for 10 pin socket
2026-07-27 Modify power schematic to fix protection circuit as well as 5V buck regulator circuit
    [VCU_Module.kicad_sch]
2026-07-27 Revert "Modify power schematic to fix protection circuit as well as 5V buck regulator circuit"
    This reverts commit bc30f46e6df5da6b476786776fb32856b4eceb90.
    [VCU_Module.kicad_sch]
2026-07-27 Reapply "Modify power schematic to fix protection circuit as well as 5V buck regulator circuit"
    This reverts commit ed7789357b0451a30a57dedadf80f61adec4e840.
    [VCU_Module.kicad_sch]
2026-07-28 updated pcb from sohams adjustments to schematic
    [MCU.kicad_sch, VCU_Module.kicad_pcb, VCU_Module.kicad_sch]
2026-07-31 notes for changes from andrew
    [VCU_Module.kicad_sch]
2026-08-02 schematic complete with new fuse holder and specs, just need to run ERC once more PCB component placement and traces done, still need to fix some DRC Errors and check warnings Still need to ensure al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
    [MCU.kicad_sch, VCU_Module.kicad_pcb, VCU_Module.kicad_sch]
2026-08-02 finished DRC checks and ERC checks in schematic and PCB, added many new components with purchase links to BOM, still need to double check previously added parts in BOM to ensure they are sufficient f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
    [MCU.kicad_sch, VCU_Module.csv, VCU_Module.kicad_pcb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]
2026-08-03 finalized BOM
    [MCU.kicad_sch, VCU_Module.kicad_sch]
2026-08-03 Removed temporary and build files
    [VCU_Module.csv]
2026-08-03 Clean up of libraries and some ERC and DRC fixes
    [MCU.kicad_sch, VCU_Module.kicad_pcb, VCU_Module.kicad_sch]
2026-08-03 final PCB fix
    [MCU.kicad_sch, VCU_Module.kicad_pcb, VCU_Module.kicad_sch]
2026-08-03 Updating 3D Model Path
    [VCU_Module.kicad_pcb]
2026-08-03 updating components with AEC certified ones
    [MCU.kicad_sch, VCU_Module.kicad_pcb, VCU_Module.kicad_sch]
2026-08-04 add 3d model
    [VCU_Module.kicad_pcb]
2026-08-04 running build makefile and fixing errors
    [MCU.kicad_sch, VCU_Module.kicad_pcb, VCU_Module.kicad_sch]
2026-08-05 Successful run of build Makefile
    [MCU.kicad_sch, VCU_Module.kicad_pcb, VCU_Module.kicad_sch]
2026-08-13 Organizing Repository
    [MCU.kicad_sch, POWER.kicad_sch, VCU_Module.kicad_pcb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]
2026-08-13 update gitignore to not ignore renderings
    [VCU_Module-outline.dxf]
2026-08-13 update libraries
    [VCU_Module.kicad_pcb]
2026-08-13 move STLink connector and change component to correct version with alignment tabs
    [VCU_Module.kicad_pcb]
2026-08-13 move stdc14 connector reroute traces fix drc and schematic parity issues rerun make for build files
    [VCU_Module-outline.dxf, VCU_Module.kicad_pcb]
